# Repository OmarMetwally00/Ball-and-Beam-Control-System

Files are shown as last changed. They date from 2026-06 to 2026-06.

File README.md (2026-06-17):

# Ball and Beam Control System

<p align="center">
  
</p>

## Overview

The Ball and Beam System is a classical unstable control problem widely used in control engineering education and research. The objective is to control the position of a rolling ball along a beam by adjusting the beam inclination angle through a servo motor using a closed-loop PID controller.

This project presents the complete development cycle of a real Ball and Beam prototype following the **VDI 2206 Mechatronic Design Methodology**, including:

* Mechanical Design
* CAD Modeling
* Finite Element Analysis (FEA)
* Mathematical Modeling
* PID Controller Design
* MATLAB Simulation
* Simulink Simulation
* Arduino-Based Real-Time Control
* Hardware–Software Integration
* System Identification
* Experimental Validation

----

# Project Highlights

| Feature | Status |
| --- | --- |
| CAD Design | ✅ |
| Mechanical Analysis | ✅ |
| Finite Element Analysis | ✅ |
| Mathematical Modeling | ✅ |
| Transfer Function Derivation | ✅ |
| PID Controller Design | ✅ |
| MATLAB Simulation | ✅ |
| Simulink Simulation | ✅ |
| Arduino Implementation | ✅ |
| System Identification | ✅ |
| Experimental Validation | ✅ |
| VDI 2206 Methodology | ✅ |

---

# Hardware Prototype

<p align="center">
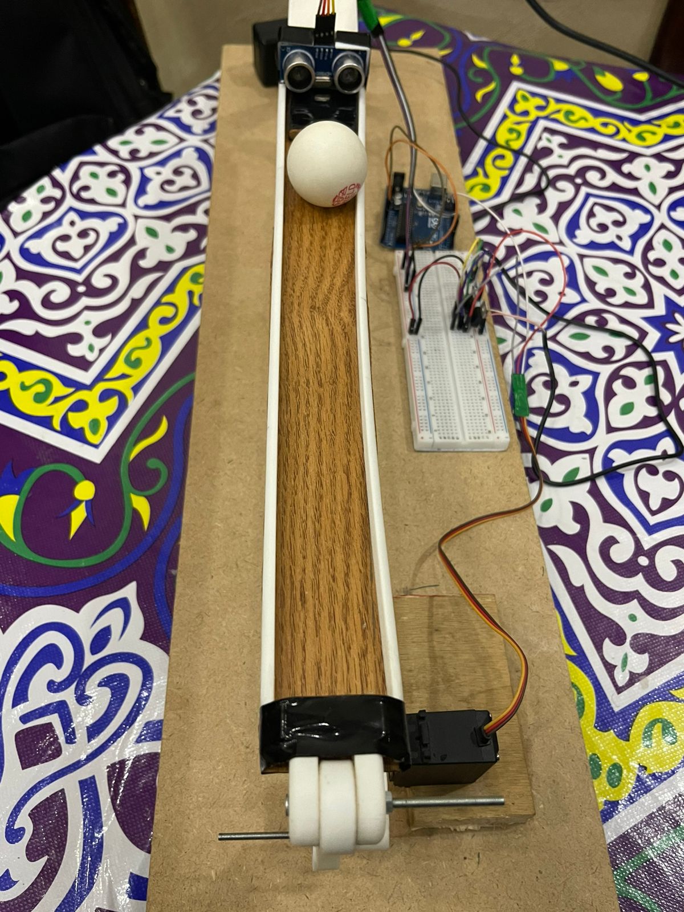
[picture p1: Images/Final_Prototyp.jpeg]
  
</p>

The physical prototype was developed and experimentally validated using:

* Arduino Uno
* MG995 Servo Motor
* HC-SR04 Ultrasonic Sensor
* Custom Mechanical Structure
* Voltage Regulation Circuit
* 12V Power Supply

---

# CAD Design

<p align="center">
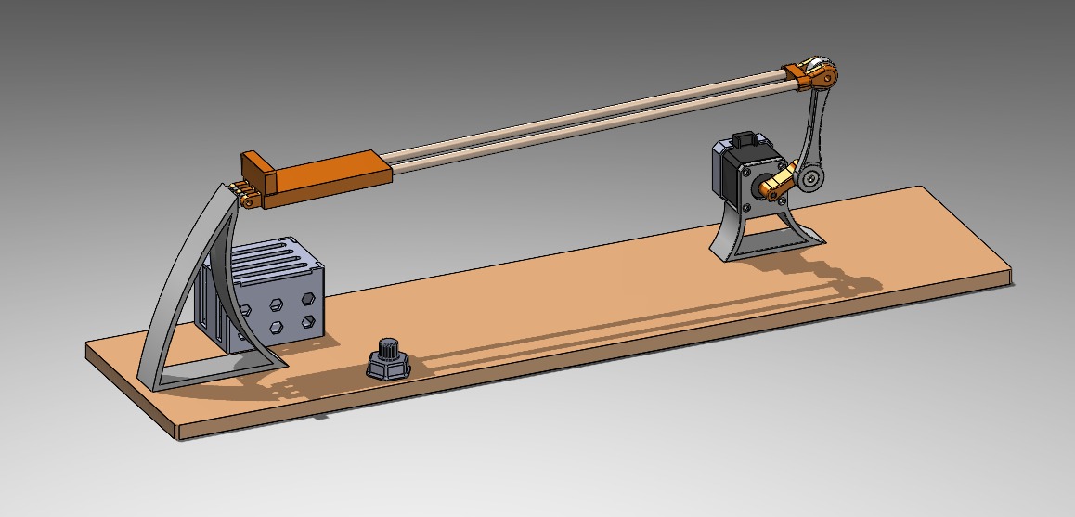
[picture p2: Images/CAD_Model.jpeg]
  
</p>

The complete mechanical assembly was designed and validated before fabrication.

Main subsystems include:

* Beam Assembly
* Linkage Mechanism
* Servo Mount
* Sensor Holder
* Structural Base

---

# System Architecture

```text
Reference Position
        │
        ▼
PID Controller
        │
        ▼
Arduino Uno
        │
        ▼
MG995 Servo Motor
        │
        ▼
Beam Angle
        │
        ▼
Ball Position
        │
        ▼
HC-SR04 Sensor
        │
        └──────────── Feedback
```

---

# Electronic Circuit

<p align="center">
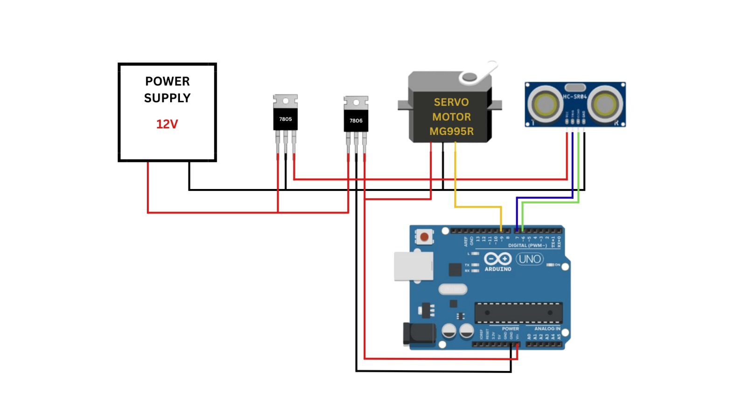
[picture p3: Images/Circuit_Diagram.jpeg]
  
</p>

The control system consists of an Arduino Uno, MG995 servo motor, HC-SR04 ultrasonic sensor, voltage regulation stage, and external power supply.

---

# VDI 2206 Engineering Workflow

The project was developed following the VDI 2206 methodology for mechatronic systems design.

This approach integrates:

1. Requirements Definition
2. Mechanical Design
3. Electronics Design
4. Software Development
5. System Integration
6. Validation and Testing

---

# Mathematical Modeling

The Ball and Beam system behaves as a double integrator and is inherently unstable in open-loop operation.

Plant Transfer Function:

P(s) = 5.532 / s²

This characteristic requires feedback control to stabilize the ball position.

---

# Control System Design

## Open-Loop Behavior

The open-loop response demonstrates unstable system behavior where the ball position continuously diverges from the desired position.

<p align="center">
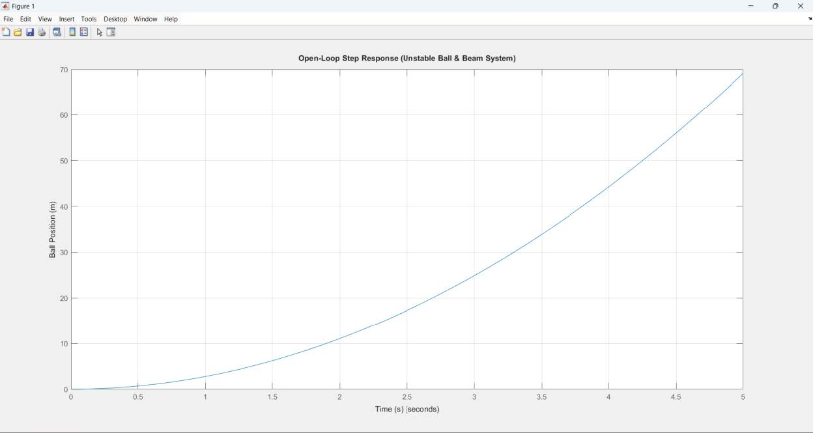
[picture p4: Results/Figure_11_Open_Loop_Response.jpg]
  
</p>

---

## Root Locus Analysis

Root locus analysis was used to investigate system stability and select suitable controller parameters.

<p align="center">
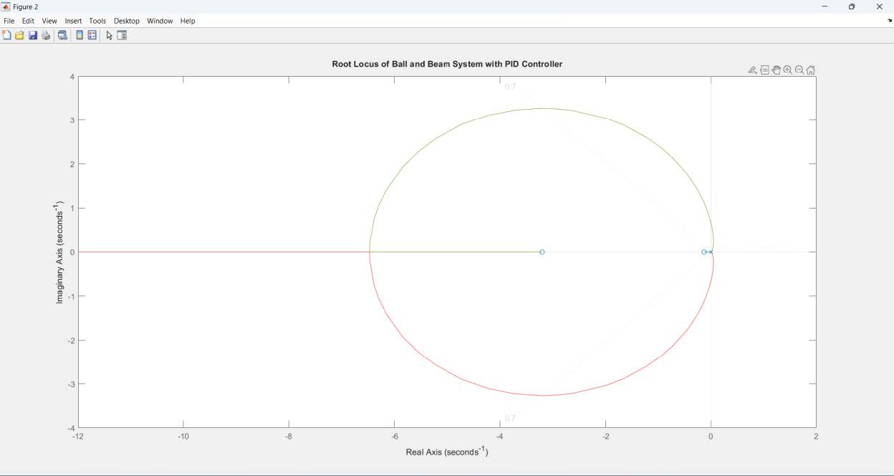
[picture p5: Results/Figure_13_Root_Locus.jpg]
  
</p>

---

## PID Controller Design

Selected controller gains:

```matlab
Kp = 40
Ki = 5
Kd = 12
```

These values provided a good balance between:

* Fast Response
* Small Overshoot
* Zero Steady-State Error
* Acceptable Settling Time

---

## Closed-Loop Response

The PID controller successfully stabilized the system and achieved accurate ball position tracking.

<p align="center">
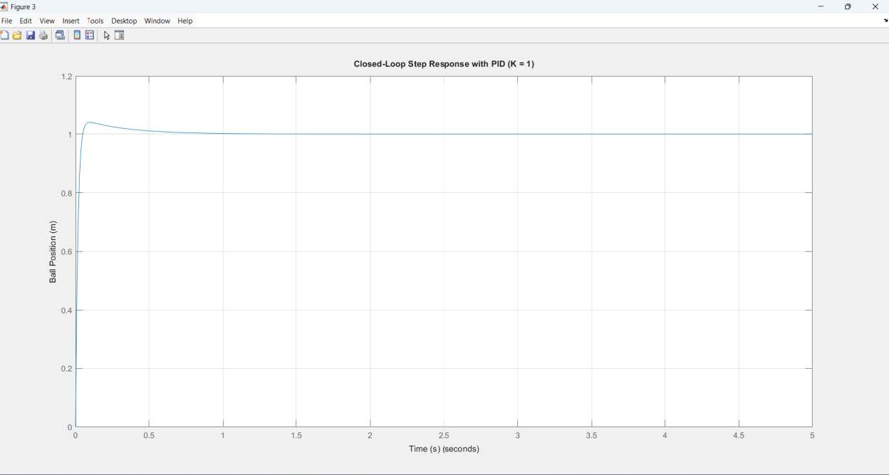
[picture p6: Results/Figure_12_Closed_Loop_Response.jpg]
  
</p>

---

# PID Tuning Analysis

## Effect of Proportional Gain (Kp)

<p align="center">
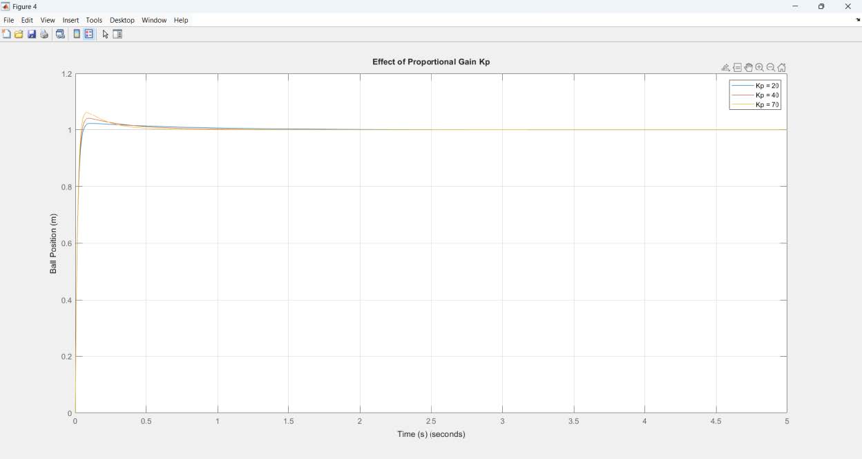
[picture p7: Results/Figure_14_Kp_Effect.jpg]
  
</p>

Increasing Kp improves response speed but may increase overshoot.

---

## Effect of Integral Gain (Ki)

<p align="center">
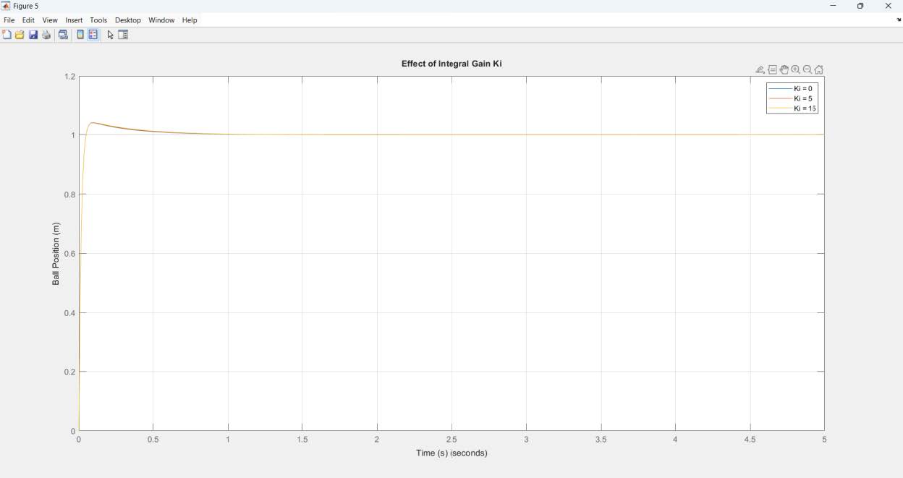
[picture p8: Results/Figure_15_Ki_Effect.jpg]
  
</p>

Increasing Ki reduces steady-state error and improves tracking accuracy.

---

## Effect of Derivative Gain (Kd)

<p align="center">
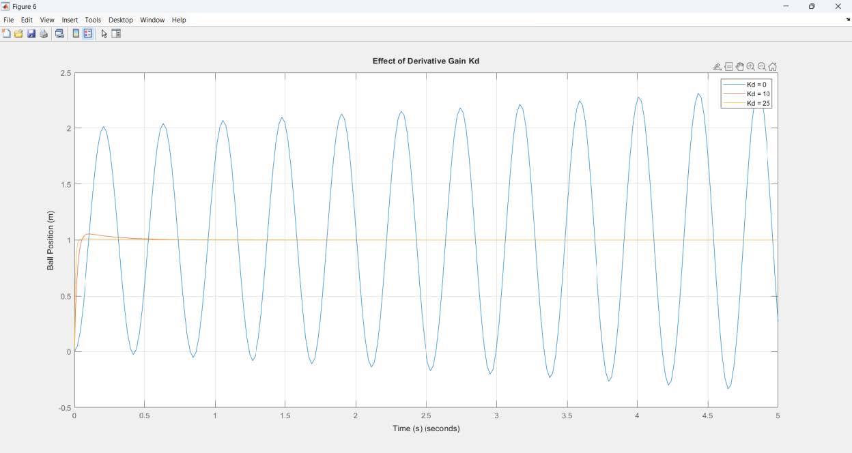
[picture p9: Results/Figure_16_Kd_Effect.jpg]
  
</p>

Derivative action increases damping and reduces oscillations.

---

# Simulink Modeling

## Open-Loop Simulink Model

<p align="center">
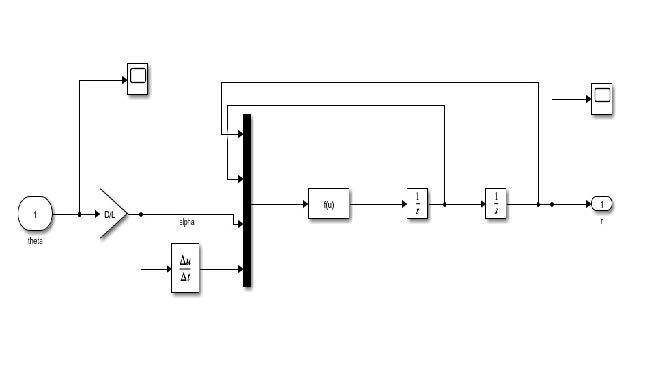
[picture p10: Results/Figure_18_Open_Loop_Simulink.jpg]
  
</p>

---

## Closed-Loop Simulink Model

<p align="center">
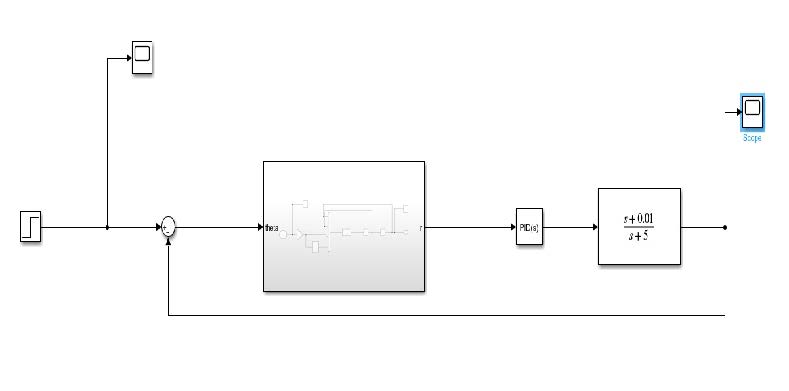
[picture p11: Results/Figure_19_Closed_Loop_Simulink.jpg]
  
</p>

---

# Hardware–Software Integration

The PID controller was implemented on Arduino and connected to MATLAB using serial communication.

Features:

* Real-time data acquisition
* Live response visualization
* Closed-loop monitoring
* Performance analysis

<p align="center">
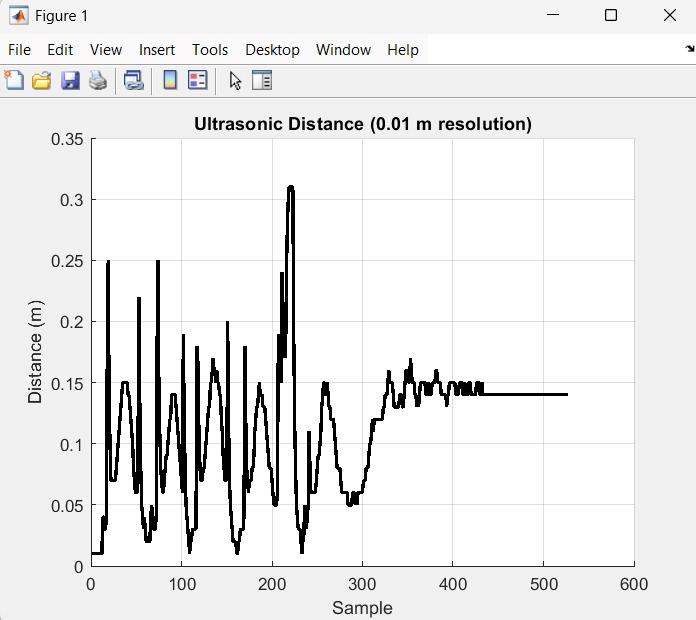
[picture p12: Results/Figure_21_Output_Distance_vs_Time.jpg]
  
</p>

---

# System Identification

Experimental data were collected from the physical prototype and processed using MATLAB System Identification Toolbox.

Identified Models:

Model 1

P(s) = (1.625s + 2.959) / (s² + 15.09s + 12850)

Model 2

P(s) = (25.05s + 39.11) / (s² + 87.88s + 1.494 × 10⁻¹⁰)

---

## System Identification Toolbox

<p align="center">
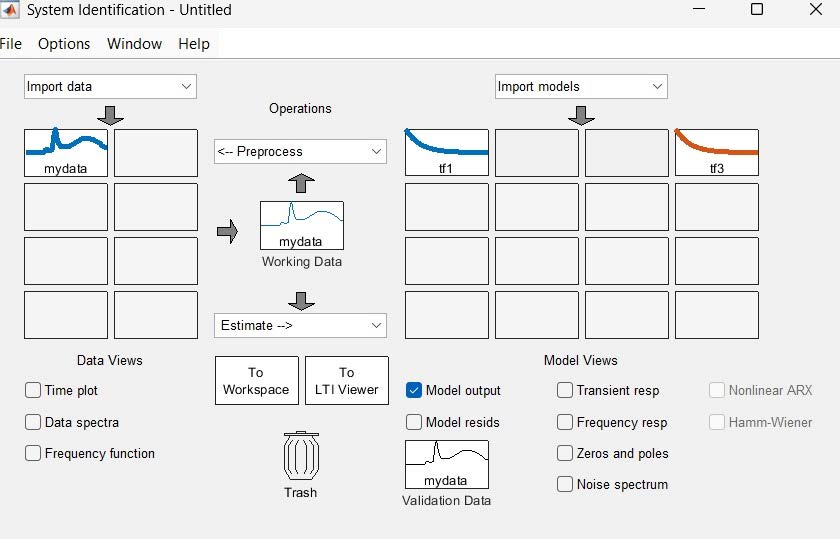
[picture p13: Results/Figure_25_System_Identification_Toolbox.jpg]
  
</p>

---

# Theoretical vs Practical Validation

One of the most important contributions of this project is the comparison between theoretical and experimentally identified models.

<p align="center">
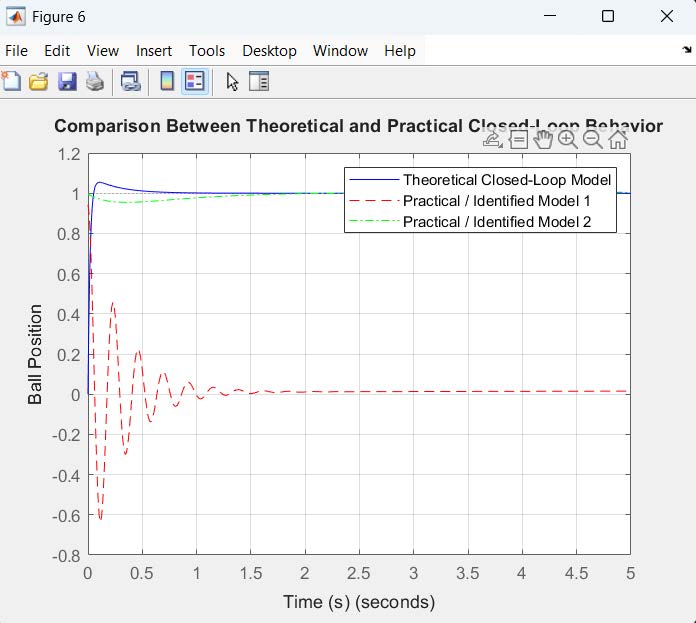
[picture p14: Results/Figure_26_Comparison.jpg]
  
</p>

---

## Performance Comparison

| Model | Overshoot (%) | Settling Time (s) | Steady-State Error |
| --- | --- | --- | --- |
| Theoretical Model | 5.43 | 0.364 | 0 |
| Practical Model 1 | 0.00 | 1005.137 | 0 |
| Practical Model 2 | 0.77 | 0.000 | 0 |

---

# Finite Element Analysis (FEA)

## Connecting Link Displacement

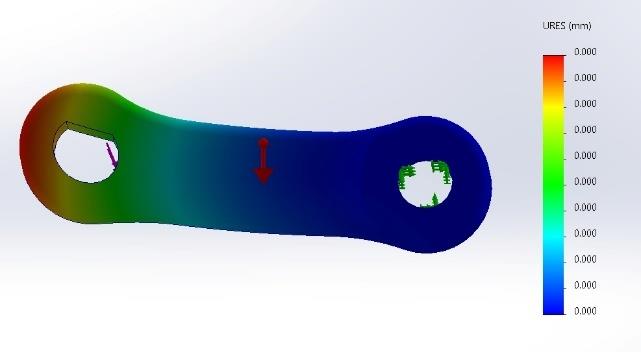
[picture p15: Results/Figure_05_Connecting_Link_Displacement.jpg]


## Connecting Link Stress Distribution

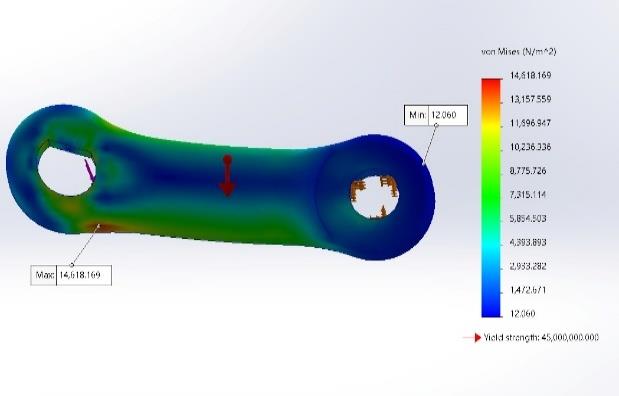
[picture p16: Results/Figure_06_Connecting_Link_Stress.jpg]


## Mesh and Boundary Conditions



## Beam Stress Distribution

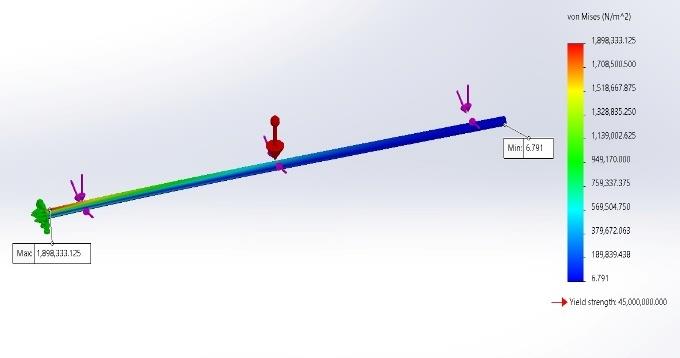
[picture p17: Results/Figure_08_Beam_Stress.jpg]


## Beam Displacement Distribution

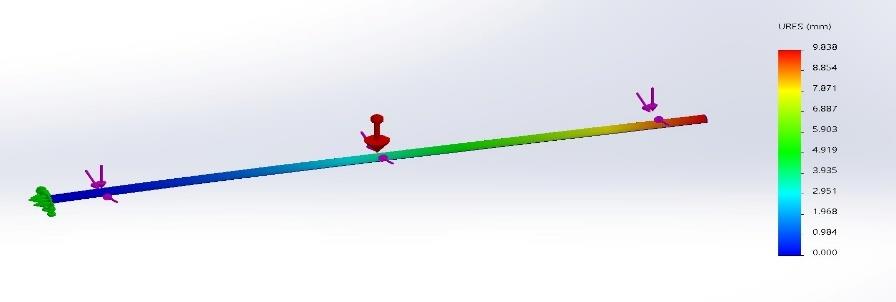
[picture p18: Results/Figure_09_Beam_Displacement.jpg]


---

# Team Members

* Mahmoud Mohamed Shamekh
* Omar Mahmoud Metwally
* Youssef Mostafa Ayad
* Ebrahim Magdy Ebrahim

---

# Supervision

Dr. Amro Shafik

Eng. Mohamed Ashraf

---

# License

This repository is published for educational, academic, and research purposes.

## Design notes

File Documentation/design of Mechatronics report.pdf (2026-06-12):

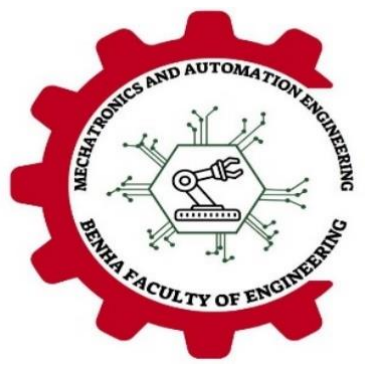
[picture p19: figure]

### 12 June 2026

Benha University

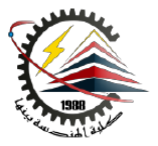
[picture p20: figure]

Benha Faculty of Engineering

Mechatronics and Automation Engineering Program

MAM 301 Design of Mechatronics

Design project

Student names: Mahmoud Mohamed Shamekh

Omar Mahmoud Metwally

Youssef Mostafa Ayad

Ebrahim Magdy Ebrahim

Supervisor Name: Dr/ Amro Shafik

Eng/ Mohamed Ashraf

Symbol | Description | Unit
( x ) | Ball position along the beam | m
( x ̇ ) | Ball linear velocity | m/s
( x ̈) | Ball linear acceleration | m/s²
( α ) | Beam inclination angle | rad
( α̇ ) | Beam angular velocity | rad/s
( α̈) | Beam angular acceleration | rad/s²
( θ ) | Servo motor shaft angle | rad
( θ ̇ ) | Servo motor angular velocity | rad/s
(θ ̈ | Servo motor angular acceleration | rad/s²
( m ) | Mass of the ball | kg
( mb ) | Mass of the beam | kg
( r ) | Radius of the ball | m
( L ) | Length of the beam | m
( R ) | Distance from beam pivot to ball | m

( d ) | Lever arm length | m
( J ) | Moment of inertia of the ball | kg·m²
( Jb ) | Moment of inertia of the beam | kg·m²
( Jm ) | Motor rotor inertia | kg·m²
( g ) | Gravitational acceleration | m/s²
( τ ) | Applied torque | N·m
( τm ) | Motor torque | N·m
( Va ) | Motor armature voltage | V
( Ia ) | Motor armature current | A
( Ra ) | Motor armature resistance | Ω
( La ) | Motor armature inductance | H
( Kt ) | Motor torque constant | N·m/A
( Ke ) | Motor back-EMF constant | V·s/rad
( b ) | Equivalent viscous damping coefficient | N·s/m
( bm ) | Motor viscous damping coefficient | N·m·s/rad
( Ff ) | Friction force | N
( P(s) ) | Ball and Beam plant transfer function | m/rad
( C(s) ) | PID controller transfer function | —
( Kp ) | Proportional gain | —
( Ki ) | Integral gain | —
( Kd ) | Derivative gain | —
( ωn ) | Natural frequency | rad/s
( ζ ) | Damping ratio | —
( e{ss} ) | Steady-state error | —

# Abstract

This project presents the systematic design, modeling, simulation, and implementation of a

Ball and Beam control system following the VDI 2206 V-Model for mechatronic system

development. The Ball and Beam system represents a classical unstable control problem that

integrates mechanical design, electronics, sensing, and control engineering. The primary

objective is to achieve accurate and stable positioning of a rolling ball along a beam by

regulating the beam angle using a feedback control strategy.

The development process begins with needs analysis and product design specifications,

followed by conceptual design and component selection. A mathematical model of the system

is derived using Newtonian mechanics, considering the rolling dynamics of the ball and small-

angle approximations. Based on the obtained model, a PID controller is designed to stabilize

the inherently unstable system and meet performance requirements such as low overshoot,

short settling time, and minimal steady-state error. MATLAB/Simulink is used for system

simulation and controller tuning, while Hardware-in-the-Loop (HIL) techniques are applied to

validate the control strategy before real-time implementation.

Finally, the controller is implemented on an Arduino microcontroller, and experimental results

are compared with simulation outcomes. The results demonstrate good agreement between

theoretical, simulated, and practical behavior, confirming the effectiveness of the V-Model

approach in developing a reliable mechatronic control system.

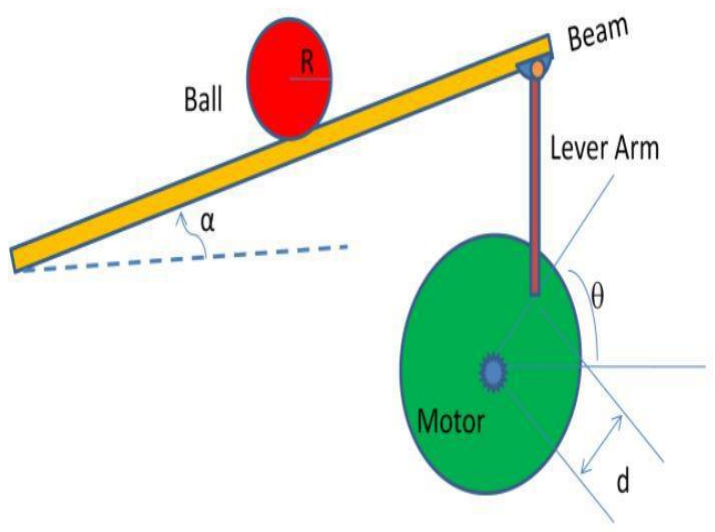
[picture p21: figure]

# Conceptual Design for Ball and Beam system

### 1. Problem Definition[2]

The objective of the Ball and Beam system is to

control the position of a ball along a beam by

adjusting the beam’s inclination angle using an

actuator. The control goal is to balance the ball at a

desired position or make it track a reference position

with high accuracy.

### 2. System Objectives

1. Maintain stable balance of the ball on the beam without falling
2. Accurately control the ball position
3. Provide fast response to disturbances and reference changes
4. Allow easy tuning and calibration

### 3. System Needs

- Continuous measurement of the ball position
- Precise adjustment of the beam angle
- Real-time execution of the control algorithm
- Data visualization and/or logging
- High accuracy and stability
- Reliable operation
- Reasonable cost for educational use
- Electrical and mechanical safety

### 4. System Specifications

Parameter | Specification | Parameter | Specification
Beam Length (L) | 35cm | Controller | PID
Ball Radius (r) | 15–20 mm | Power Supply | 12 V DC
Ball Mass (m) | 50–100 g | microcontroller | Arduino
Beam Angle Range (α) | ±15° | Overshoot | < 10%
Position Accuracy | ±2 mm | Actuator | Servo Motor MG995
Settling Time | < 3 s | Sensor | Ultrasonic

### 5. Constraints

### 5.1 Safety Constraints

- Mechanical end-stops to limit beam rotation
- Electrical insulation and proper grounding
- Overcurrent and overvoltage protection

### 5.2 Environmental Constraints

- Indoor laboratory operation only
- Operating temperature range: 0–40 °C
- Low vibration and dust-free environment
- No exposure to moisture or corrosive substances

### 5.3 Manufacturability Constraints

- Use of commercially available components
- Simple machining processes (3D printing)
- Modular design for easy assembly and replacement
- Low manufacturing and maintenance cost

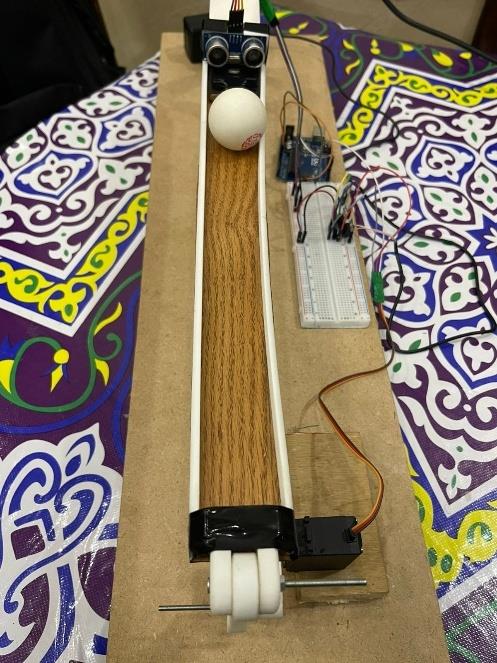
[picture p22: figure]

Figure 1:the system

6.

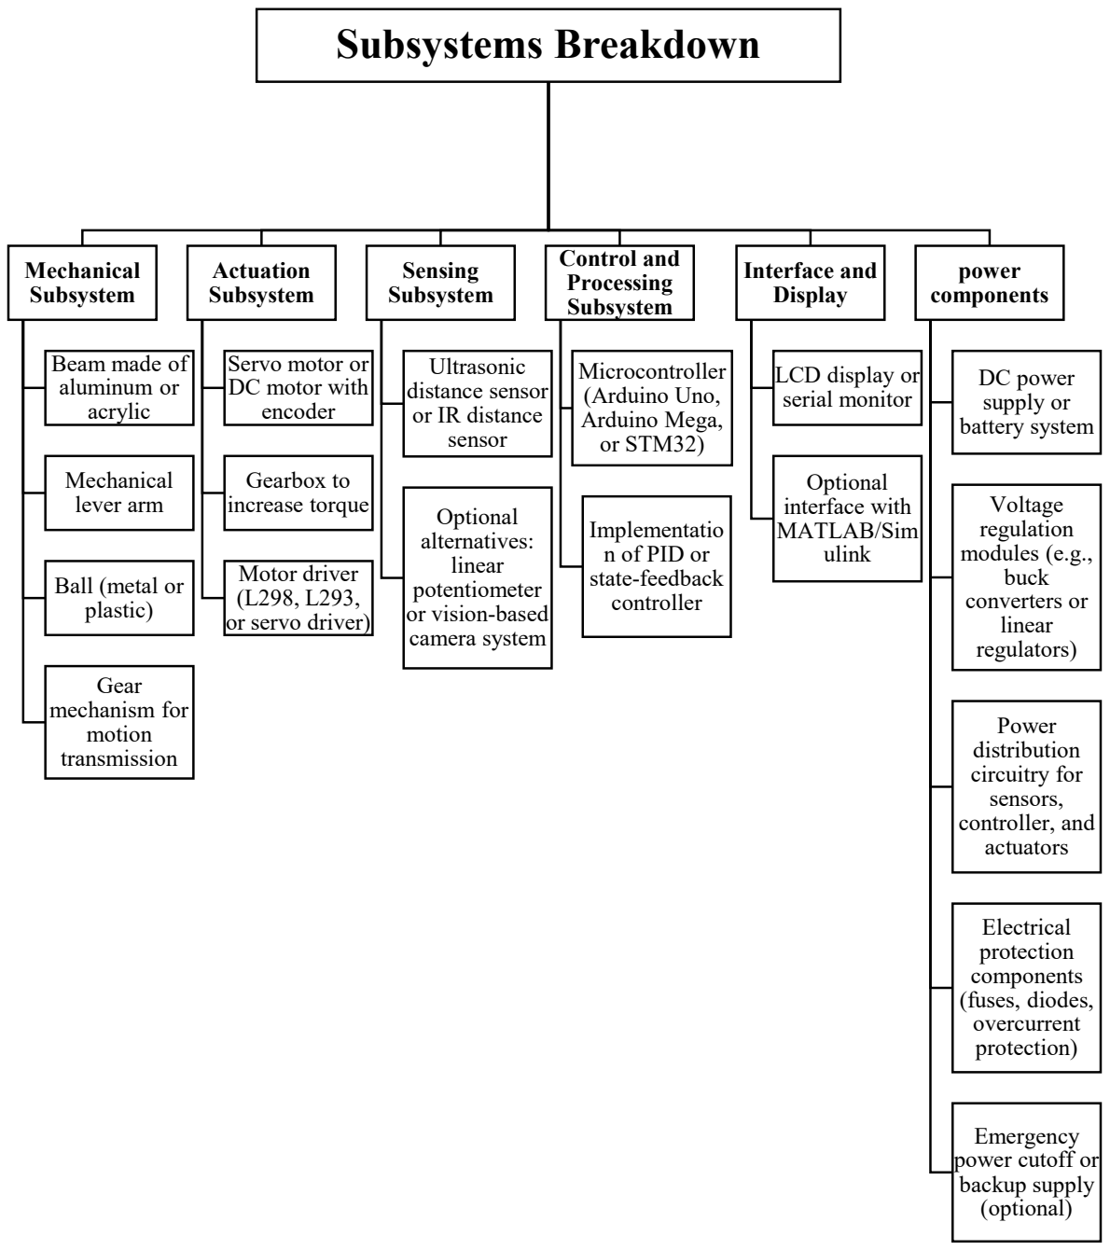
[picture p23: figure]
Subsystems Breakdown; Mechanical Subsystem; Beam made of aluminum or acrylic; Mechanical lever arm; Ball (metal or plastic); Gear mechanism for motion transmission; Actuation Subsystem; Servo motor or DC motor with encoder; Gearbox to increase torque; Motor driver (L298, L293, or servo driver); Sensing Subsystem; Ultrasonic distance sensor or IR distance sensor; Optional alternatives: linear potentiometer or vision-based camera system; Control and Processing Subsystem; Microcontroller (Arduino Uno, Arduino Mega, or STM32); Implementatio n of PID or state-feedback controller; Interface and Display; LCD display or serial monitor; Optional interface with MATLAB/Sim ulink; power components; DC power supply or battery system; Voltage regulation modules (e.g., buck converters or linear regulators); Power distribution circuitry for sensors, controller, and actuators; Electrical protection components (fuses, diodes, overcurrent protection); Emergency power cutoff or backup supply (optional)

### 7. Design Alternatives

Design Alternative | DA₁ | DA₂ | DA₃
Sensor Type | Ultrasonic | IR Sensor | Camera Vision
Actuator | Servo Motor | DC Motor + Encoder | Stepper Motor
Control Method | PID | PI | State-Space
med Controller | Arduino Uno | Arduino Mega | STM32
Cost | Medium | High | High
Complexity | Low | Medium | High

### 8. Design Evaluation Criteria

Criterion | Weight | DA1 | DA2 | DA3
Accuracy | 0.30 | 0.7 | 0.9 | 0.6
Stability | 0.40 | 0.9 | 0.7 | 0.6
Cost | 0.10 | 0.9 | 0.5 | 0.6
Ease of Implementation | 0.20 | 0.6 | 0.8 | 0.7
evaluation | 1 | 0.78 | 0.76 | 0.66

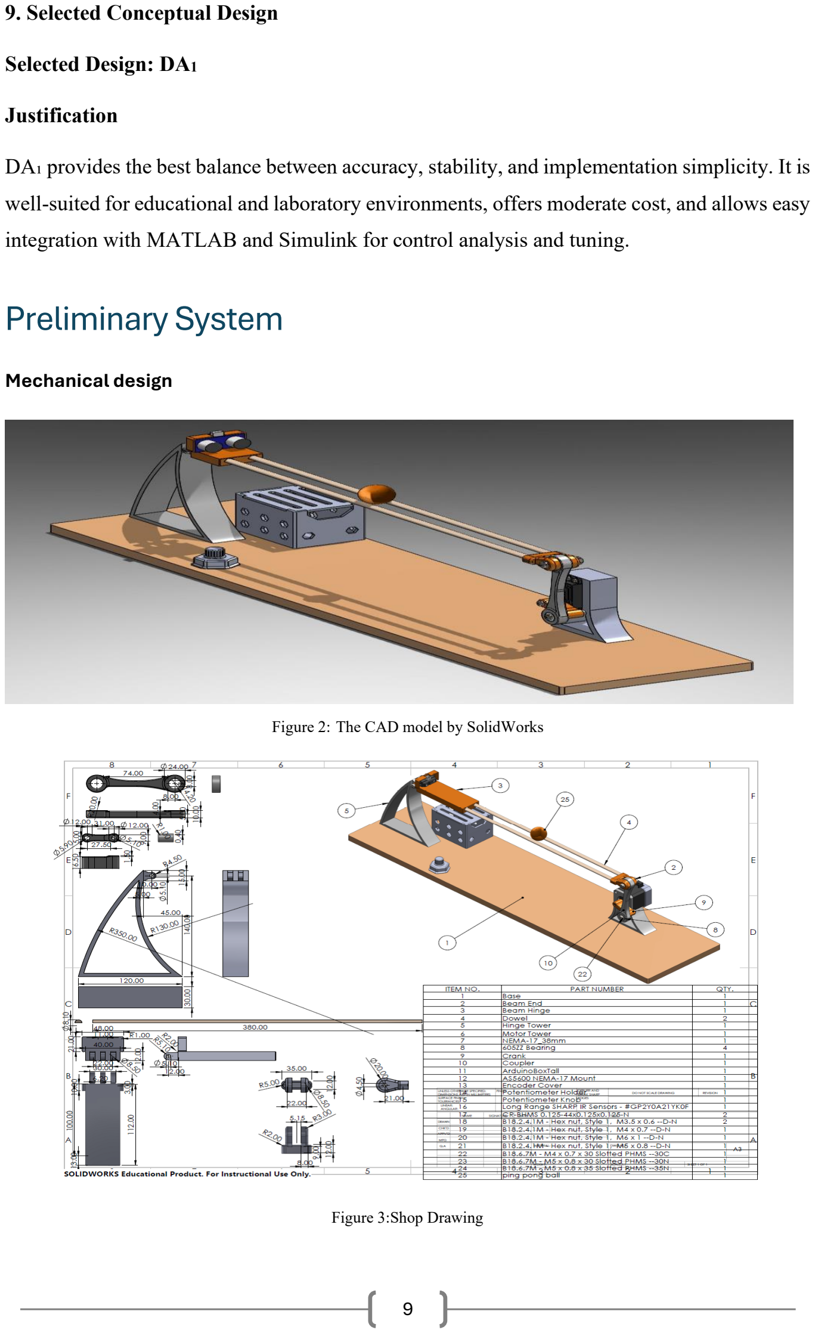
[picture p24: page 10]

### 9. Selected Conceptual Design

Selected Design: DA1

Justification

DA₁ provides the best balance between accuracy, stability, and implementation simplicity. It is

well-suited for educational and laboratory environments, offers moderate cost, and allows easy

integration with MATLAB and Simulink for control analysis and tuning.

# Preliminary System

### Mechanical design

Figure 2: The CAD model by SolidWorks

Figure 3:Shop Drawing

2.preliminary electronic/control circuit diagram

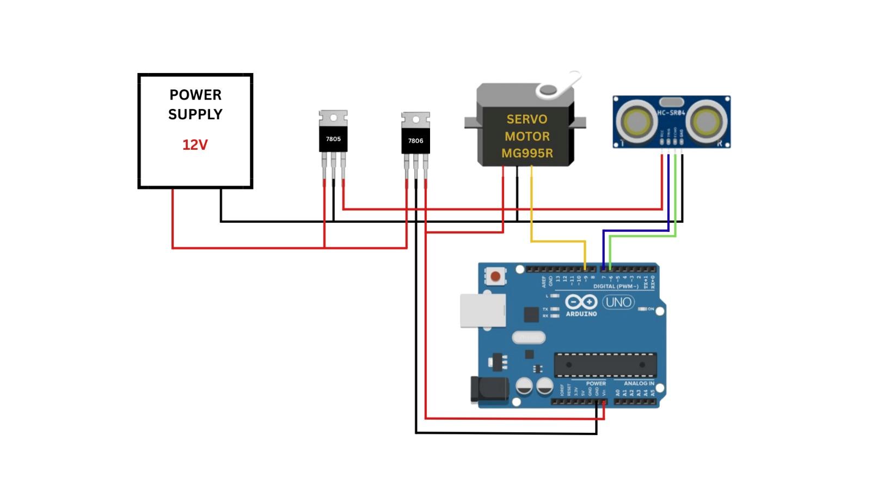
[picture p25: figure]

Figure 4:Circuit diagram

3.All components and their interfaces

No. | Component | Type | Function in System | Input Interface | Output Interface | Interface Type
1 | Ball | Mechanical | Object to be balanced on the beam | Beam inclination angle (α) | Ball position (x) | Mechanical (Contact & Gravity)
2 | Beam | Mechanical | Supports the ball and transfers tilt motion | Rotation from lever arm | Linear motion of the ball | Mechanical (Rotational → Translational)
3 | Lever Arm | Mechanical | Converts servo rotation to beam tilt | Servo shaft rotation (θ) | Beam angular displacement (α) | Mechanical (Rotational Linkage)

4 Servo | Motor (MG995R) | Actuator | Controls beam angle | PWM signal from Arduino | Shaft rotation (θ) | Electrical (PWM) → Mechanical
5 Ultrasonic | Sensor (HC-SR04) | Sensor | Measures ball position on beam | Trigger pulse from Arduino | Echo pulse proportional to distance | Digital Electrical (Trigger/Echo)
6 Arduino | Uno | Controller | Main control and signal processing unit | Sensor signals (Echo), Power (5V) | PWM to servo, Trigger to sensor | Digital Electrical
7 Control | Algorithm (PID) | Software | Stabilizes ball position | Ball position error | Control signal (PWM duty cycle) | Logical / Software Interface
8 Power | Supply (12V DC) | Electrical | Provides power to system | AC/DC input | 12V DC output | Electrical Power
9 Voltage | Regulator (7805) | Electrical | Steps down voltage for logic | 12V DC | 5V DC | Electrical Power
10 Voltage | Regulator (7806) | Electrical | Steps down voltage for servo | 12V DC | 6V DC | Electrical Power

11 Mechanical | Base & Frame | Structural | Supports all components | Static loads | Structural stability | Mechanical
12 Wiring & | Connectors | Electrical | Signal & power transmission | Electrical signals | Electrical signals | Electrical

# Mechanical Design, Kinematics, and FEA

System Overview

The finalized mechanical design of the balanced beam system consists of a servo-actuated

crank–link mechanism that converts the rotational motion of the MG995 servo motor into a

controlled angular displacement of the beam. The beam is hinged at one end and supports a

rolling ball used to demonstrate balancing and control concepts.

### 2. Geometry & Dimensions

Component | Dimension
Crank length | 4.2 cm
Link length | 11.2 cm
Beam length | 35 cm
Beam cross-section | Semi-circular, Ø 8 mm
Hinge height | 14 cm
Servo rotation range | 0–180°
Beam rotation range | ±10° (approx.)

Note: All dimensions were selected to avoid singular configurations and mechanical

interference.

Material Selection

Component | Material | Reason
Beam | PLA | Lightweight, sufficient strength, easy fabrication
Link & Crank | PLA | Low inertia, ease of manufacturing
Base | Wood | Structural stability

Note: PLA provides adequate strength with a high factor of safety while minimizing weight.

Kinematic Relation

θs → Servo motor | ∅ → Link Angle | θb → Beam angle

Crank length (r)=.042m

Beam Length (lb)=.35m | | Link Length (L)=.112m

Links Analysis

Position Analysis

r cos(θS) + L cos(∅) = lb cos(θb) | | Horizontal direction
r sin(θS) + L sin(∅) = lb sin(θb) | | Vertical direction
| θb = tan⁻¹ r sin(θS) + L sin(∅) r cos(θS ) + L cos(∅)

Velocity Analysis

r θs

∙

| cos(θS) + L ∅ ∙ cos(∅) = lb θb

∙
cos(θb)

r θs

∙

| sin(θS) + L ∅ ∙ sin(∅) = lb θb

∙
sin(θb)

Acceleration Analysis

r θs

∙∙
| (−sin(θS)) + L ∅

∙∙
(sin(∅))

Ball analysis

Position

Yball = xsin(θb)

Velocity

Yball

- = xcos(θb
)θb

̇

Accelerate

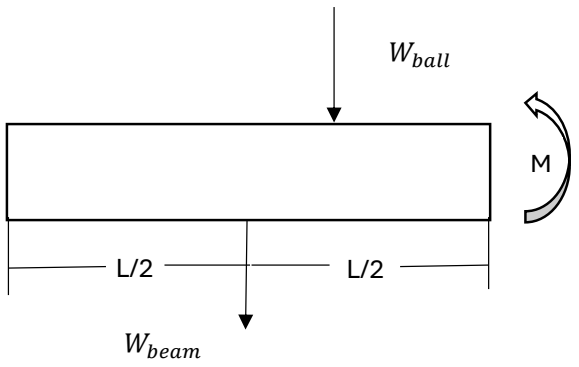
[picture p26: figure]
Wball; Wbeam

Yball ⃛ = −sinθbθb

̇

2
+ cosθbθb

̈

Dynamics

Wball = mg

Wbeam = mbeamg

Ibeam =

1
3

mblb

2 =

1
3

∗ .011 ∗ (. 35)

2 = 4.5 × 10⁻⁴

∑τ = Iθb

τball = mgxcos(θb

) | τbeam = mbeamg

l
2

cos(θb

)

∴ τeq − gcos(θb)(mballx + mbeam

l
2

) = Ibeamθb

at θbvery small → cos(θb

) = 1

at θ = 0

τmax = 9.81 ∗ (. 003x + .011 ∗ .175)

= .02943x + .0189333

at x = .35m

τ = .036 ≅ .04N/m

We selectMG995 Servo motor

Max Tourq for Servo ≈ 1.1 N/m (∴ Suitable for system)

Stress Analysis

Mmax = mballgx + mbeam

l
2

I = .11r

4 = .11(. 004)

4 = 2.8 × 10⁻¹¹m⁴

σbeam =

Mmax ∗ c
I

(at x = l)

Mmax = 9.81(. 003 ∗ .35 + .11 ∗ .175) = .029N. m

σbeam =

.029∗004
2.8∗10⁻¹¹ = 4.1 MPa | (bending stress)

V=(mball + mbeam)g = (. 003 + .011) ∗ 9.81 = .137N

τmax =

4V
3A

A =

πr

2

2

τmax = 1.1 MPa | (Shear stress)

σeq = √σbeam
2 | + 3τmax
2 | = 4.1 MPa

Summary

Stress Analysis Summary

- Maximum bending stress:

σmax ≈ 4.1 MPa

- PLA yield stress:

σy ≈ 50 MPa

- Factor of Safety:

FOS ≈ 12

Design is structurally safe.

Actuator Verification

- Required torque:

τreq ≈ 0.04 N ⋅ m

### Beam Cross Section 8∅

- MG995 available torque:

τstall ≈ 1.1 N ⋅ m

Servo motor selection is adequate with a large torque margin.

Finite Element Analysis (FEA)

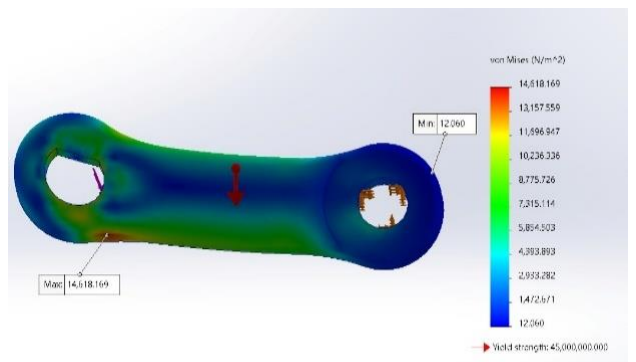
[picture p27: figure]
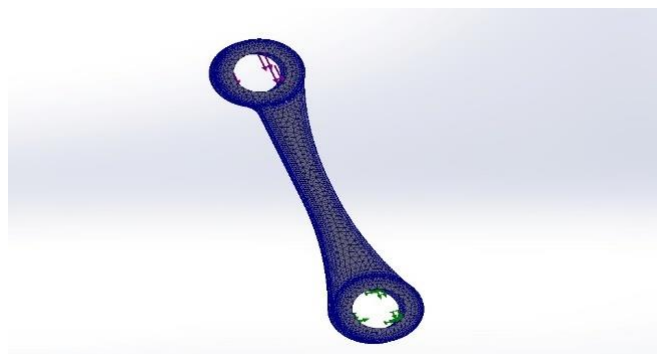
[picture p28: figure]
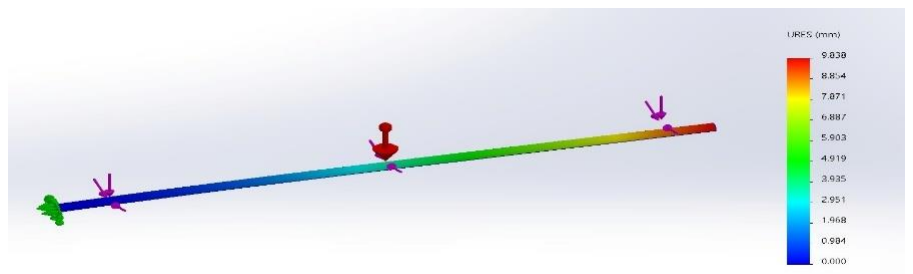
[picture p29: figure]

Figure 5 illustrates the total displacement (URES) distribution of the connecting link under the

applied load. One end of the link is constrained, while a downward force is applied near the

centre to represent the transmitted load from the crank–servo mechanism. The displacement

increases gradually from the fixed end toward the free end, reaching its maximum value at the

Figure 7:Finite element mesh and boundary conditions of the connecting link

Figure 8 : von Mises stress distribution of the beam under applied loading

Figure 9:Total displacement (URES) distribution of the beam under applied loading

Figure 5:Total displacement (URES) of the connecting link

Figure 6:von Mises stress distribution of the connecting link under applied load unconstrained side. The smooth colour gradient indicates uniform deformation without

localized instability. The overall displacement magnitude is very small, confirming that the

link has sufficient stiffness and is suitable for use in the ball and beam system.

Figure 6 shows the von Mises stress distribution of the connecting link obtained from finite

element analysis. One end of the link is constrained, while a downward load is applied to

simulate the force transmitted from the servo-driven crank mechanism. The stress is mainly

concentrated around the hole regions due to stress concentration effects caused by pin

connections. The maximum von Mises stress reaches approximately 14.6 MPa, which is

significantly lower than the material yield strength of 45 MPa. This confirms that the

connecting link operates safely without risk of plastic deformation under the applied loading

conditions.

Figure 7 shows the finite element model of the connecting link, including the applied mesh

and boundary conditions. A triangular mesh is used to accurately represent the complex

geometry of the link, with finer elements around the holes where stress concentration is

expected. The lower hole is fully constrained to simulate the fixed joint, while forces are

applied at the upper hole to represent the load transmitted from the servo-driven crank

mechanism. This meshing and boundary condition setup ensures reliable stress and

displacement results in the finite element analysis.

Figure 8 illustrates the von Mises stress distribution along the beam obtained from finite

element analysis. The beam is constrained at one end, while external forces are applied at the

mid-span and near the free end to represent the combined effect of the linkage force and the

ball weight. The maximum von Mises stress, approximately 1.9 MPa, occurs near the fixed

support due to the highest bending moment. All stress values are significantly below the

material yield strength of 45 MPa, indicating that the beam operates safely under the applied

loading conditions.

Figure 9 presents the total displacement (URES) distribution along the beam obtained from

finite element analysis. The beam is fixed at one end, while downward forces are applied at the

mid-span and near the free end to represent the effect of the ball weight and the linkage force.

The displacement increases gradually from the fixed support toward the free end, reaching a

maximum value of approximately 9.8 mm at the free end. This deformation pattern is

consistent with classical beam bending behaviour and remains within acceptable limits for the

ball and beam control system.

FEA Summary

The finite element analysis confirms that:

- Maximum stress in all components is well below the yield strength.
- Displacements are within acceptable limits for accurate ball position control.
- Stress concentrations occur mainly at holes and fixed supports, as expected.
- The mechanical design is structurally safe and suitable for the ball and beam system

driven by the MG955 servo motor

Final Mechanical Model Validation

The final mechanical design satisfies:

- Kinematic requirements
- Dynamic and torque constraints
- Stress and deflection limits
- Manufacturing feasibility

The system is therefore mechanically complete and ready for control implementation and experimental

testing.

The mechanical design of the balanced beam system has been finalized after verifying kinematic

performance, actuator capability, and structural integrity. The design meets all functional and safety

requirements and provides a reliable platform for control system development.

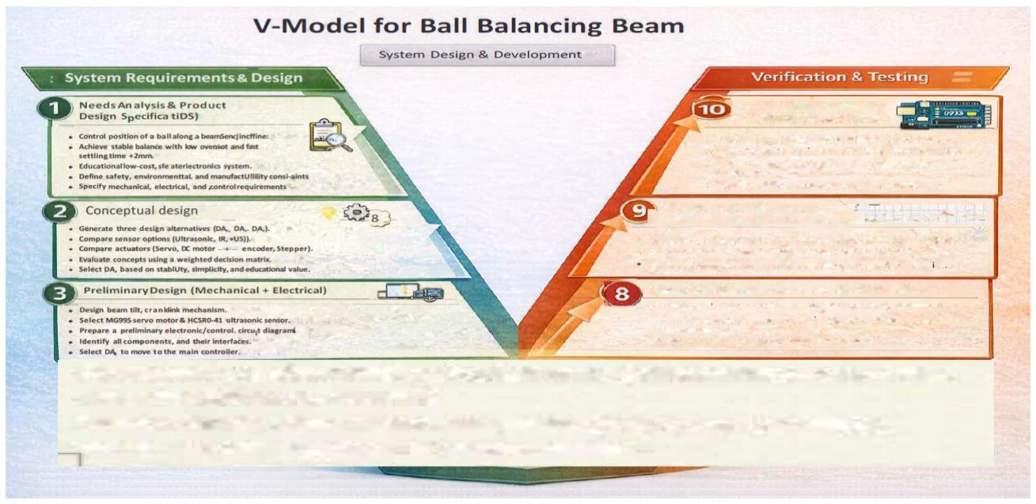
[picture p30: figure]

Figure 10: Left Side of the V-model

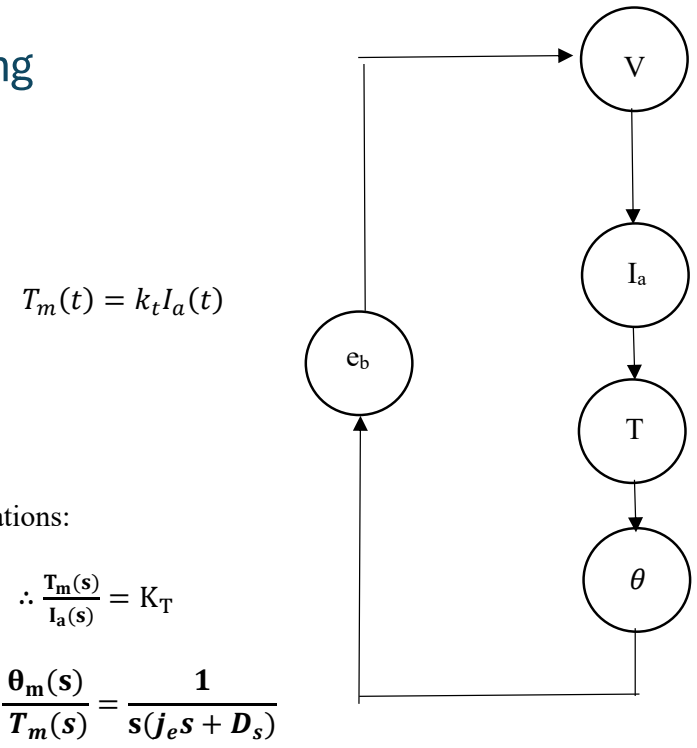
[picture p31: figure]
1 s(jes + Ds)

# Mathematical Modeling

Motor Modeling:

Va = La

Ia

∙
(t) + Ra
Ia

(t)

Tm(t) = jeθ

∙∙
m + Deθ

∙
m

eb = keθ

∙

by take LaPlace and sub. all the equations:

∴

I(s)
Va(s)

=

1
Las+Ra

∴

By putting the equations in Simulink

G =

KT
S(LaJeS

2 + (JeRa + DeLa
)S + RaDe)

System Equations [10]

The second derivative of the input beam angle αα affects the second derivative of the ball

position rr. However, this contribution is neglected for simplicity. The Lagrangian equation

of motion of the ball on the beam is given by:

0 = (

J
R2 +m) r̈+ mgsin α − mrα̇
2

Linearizing this equation about the equilibrium beam angle α = 0α=0, the following linear

approximation of the system is obtained:
(

J
R2 +m) r̈= −mgα

The relationship between the beam angle αα and the gear (servo) angle θθ can be

approximated by the linear relation:

α =

d
L

θ

By Substituting Equation:
(

J
R2 +m) r̈= −mg

d
L

θ

Transfer Function

Taking the Laplace transform of Equation (4), assuming zero initial conditions, gives:
(

J
R2 +m) s
2R(s) = −mg

d
L

Θ(s)

Rearranging, the transfer function from the gear angle Θ(s)Θ(s) to the ball

position R(s)R(s) is obtained as:

P(s) =

R(s)
Θ(s)

=

mgd
L (

J
R2 +m)

1
s

2 m/rad

For Our system

m = 0.0027 | Ball mass (kg)
L = 0.35 | Beam length (m)

R = L - 0.02 Distance from pivot (m)

d = 0.042 Lever arm length (m)

J = 8× 10

−7 | Ball moment of inertia (kg.m^2)
g = 9.81 | Gravity (m/s^2)

MATLAB Simulation

% ============================================================ % Benha University
% Faculty of Engineering
% Mechatronics and Automation Engineering Program % MAM 301 - Design of Mechatronics % Design Project: Ball and Beam System

% Students:
% Mahmoud Mohamed Shamekh
% Omar Mahmoud Metwally
% Youssef Mostafa Ayad
% Ebrahim Magdy Ebrahim

% Supervisors:
% Dr. Amro Shafik
% Eng. Mohamed Ashraf
% ============================================================

clc; clear; close all;

%% ============================================================ % Physical Parameters
%% ============================================================
M = 0.0027; | % Ball mass (kg)
L = 0.35; | % Beam length (m)
R = L - 0.02; | % Distance from pivot (m)
D = 0.042; | % Ball diameter (m)
r = D/2; | % Ball radius (m)
J = 8e-7; | % Ball moment of inertia (kg.m^2)
g = -9.81; | % Gravity acceleration (m/s^2)

%% ============================================================ % Ball & Beam Model Constants
%% ============================================================
A = (J/(r^2)) + M; | % Effective mass term
K = (M * g * R) / L; | % System constant

%% ============================================================ % Transfer Function
%% ============================================================ s = tf('s');

% Ball position / Beam angle transfer function
P = -(K/A) * 1/(s^2);

disp('Ball and Beam Plant Transfer Function:') P

%% ============================================================ % Open-Loop Response (Unstable)
%% ============================================================ figure
step(P,5)
grid on
title('Open-Loop Step Response (Unstable Ball & Beam System)') xlabel('Time (s)')
ylabel('Ball Position (m)')

%% ============================================================ % PID Controller Parameters
%% ============================================================
Kp = 40; | % Proportional gain
Ki = 5; | % Integral gain
Kd = 12; | % Derivative gain

% PID controller (transfer function form, without scalar gain) C0 = Kp + Ki/s + Kd*s;

%% ============================================================ % Root Locus with Variable Gain K
%% ============================================================ figure
rlocus(C0 * P)
grid on
title('Root Locus of Ball and Beam System with PID Controller') sgrid(0.7, []) % Desired damping ratio

%% ============================================================ % Gain Selection
%% ============================================================
K_gain = 1; | % Selected from root locus (adjust if needed)

C_final = K_gain * C0;
T_final = feedback(C_final * P, 1);

%% ============================================================ % Closed-Loop Response
%% ============================================================ figure
step(T_final,5)
grid on
title(['Closed-Loop Step Response with PID (K = ', num2str(K_gain), ')']) xlabel('Time (s)')
ylabel('Ball Position (m)')

%% ============================================================ % Effect of PID Parameters
%% ============================================================ % ---- Effect of Kp ----
Kp_vals = [20 40 70];
figure; hold on
for kp = Kp_vals
Ctemp = kp + Ki/s + Kd*s;
Ttemp = feedback(Ctemp * P, 1); step(Ttemp,5)
end
legend('Kp = 20','Kp = 40','Kp = 70') grid on
title('Effect of Proportional Gain Kp') xlabel('Time (s)')
ylabel('Ball Position (m)')

% ---- Effect of Ki ----
Ki_vals = [0 5 15];
figure; hold on
for ki = Ki_vals
Ctemp = Kp + ki/s + Kd*s;
Ttemp = feedback(Ctemp * P, 1); step(Ttemp,5)
end
legend('Ki = 0','Ki = 5','Ki = 15') grid on
title('Effect of Integral Gain Ki') xlabel('Time (s)')
ylabel('Ball Position (m)')

% ---- Effect of Kd ----
Kd_vals = [0 10 25];
figure; hold on
for kd = Kd_vals
Ctemp = Kp + Ki/s + kd*s;
Ttemp = feedback(Ctemp * P, 1); step(Ttemp,5)
end
legend('Kd = 0','Kd = 10','Kd = 25') grid on
title('Effect of Derivative Gain Kd')
xlabel('Time (s)')
ylabel('Ball Position (m)')
%% ============================================================ % Stability Information (Poles & Damping Table)
%% ============================================================ [wn, zeta, poles] = damp(T_final);

ResultsTable = table( ...
poles, ...
zeta, ...
wn, ...
'VariableNames', {'Pole', 'DampingRatio', 'NaturalFrequency'} ... );

disp('Closed-Loop Poles and Damping Information:') disp(ResultsTable)

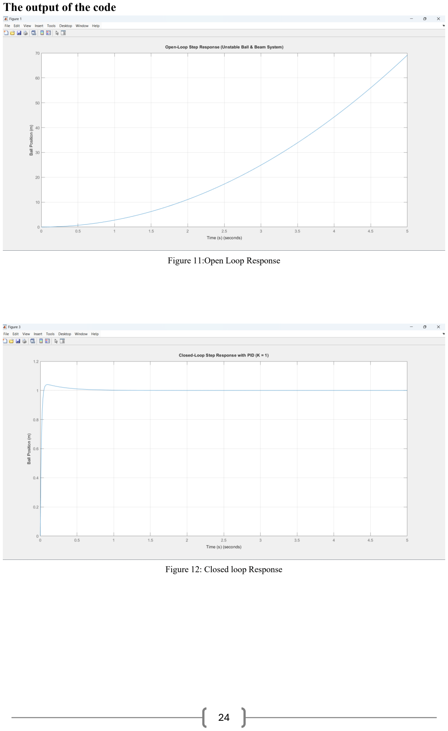
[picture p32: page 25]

The output of the code

Figure 11:Open Loop Response

Figure 12: Closed loop Response

Ball and Beam Plant Transfer Function:

P(s) =

5.532
s

2

Closed-Loop Poles and Damping Information:

Pole | Damping Ratio | Natural Frequency
-0.13007 | 1 | 0.13007
-3.3825 | 1 | 3.3825
-62.876 | 1 | 62.876

Figure 11 illustrates the open-loop step response of the ball and beam system. The response

shows that the ball position increases rapidly and continuously with time without reaching a

steady value. This unbounded growth is caused by the double integrator nature of the plant,

which makes the system unstable in open-loop operation. Any small input disturbance results

in continuous acceleration of the ball along the beam, confirming that feedback control is

essential to stabilize the system and prevent the ball from diverging.

Figure 12 presents the closed-loop step response of the ball and beam system when a PID

controller is applied. The response demonstrates a stable behavior where the ball position

quickly reaches the desired reference value with a small overshot and then settles smoothly

without sustained oscillations. The steady-state error is effectively eliminated due to the

integral action, while the derivative term provides sufficient damping. This result confirms

that the selected PID controller parameters successfully stabilize the ball and beam system

and significantly improve its transient and steady-state performance compared to the open-

loop case.

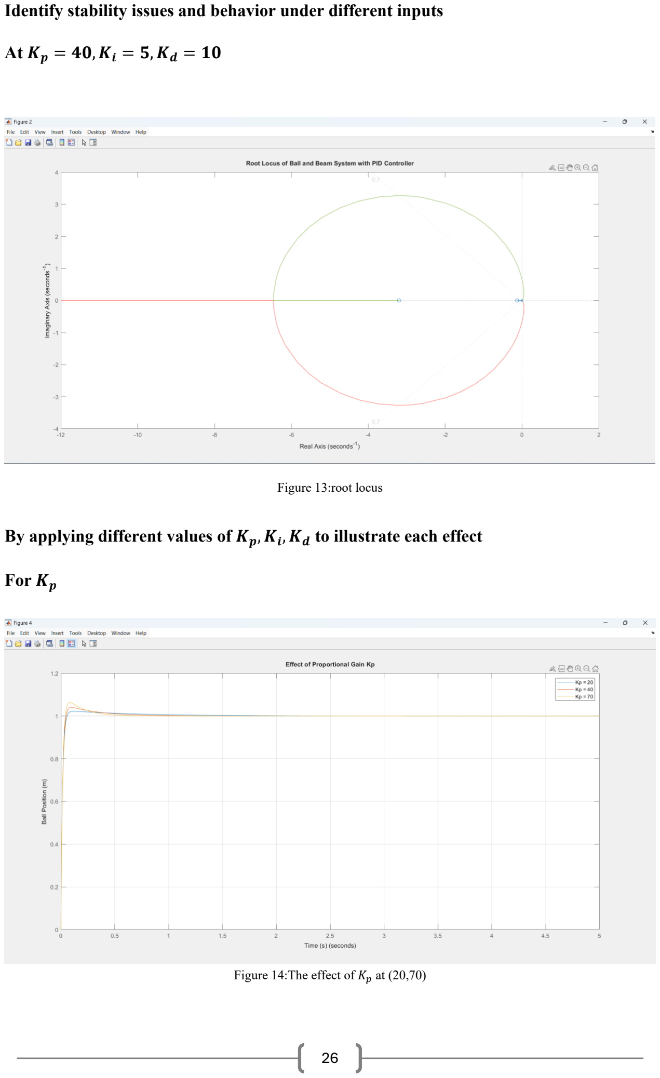
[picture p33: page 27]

Identify stability issues and behavior under different inputs

At Kp = 40, Ki = 5, Kd = 10

By applying different values of Kp, Ki

, Kd to illustrate each effect

For Kp

Figure 13:root locus

Figure 14:The effect of Kp at (20,70)

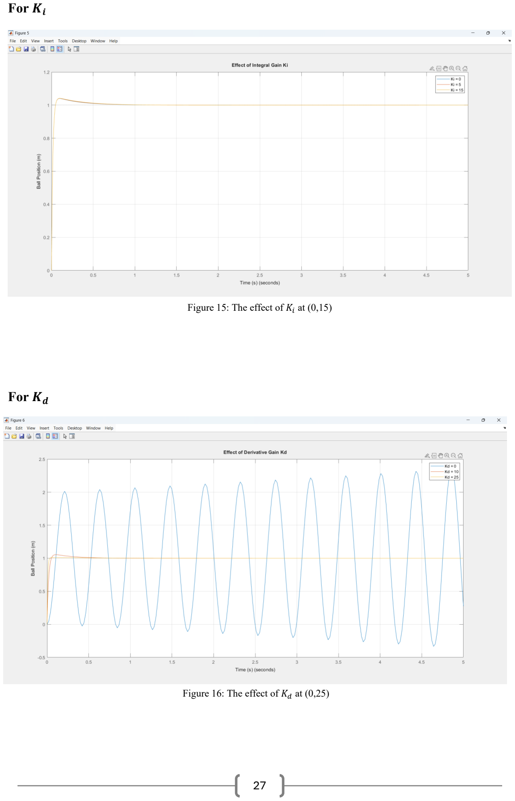
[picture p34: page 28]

For Ki

For Kd

Figure 15: The effect of Ki at (0,15)

Figure 16: The effect of Kd at (0,25)

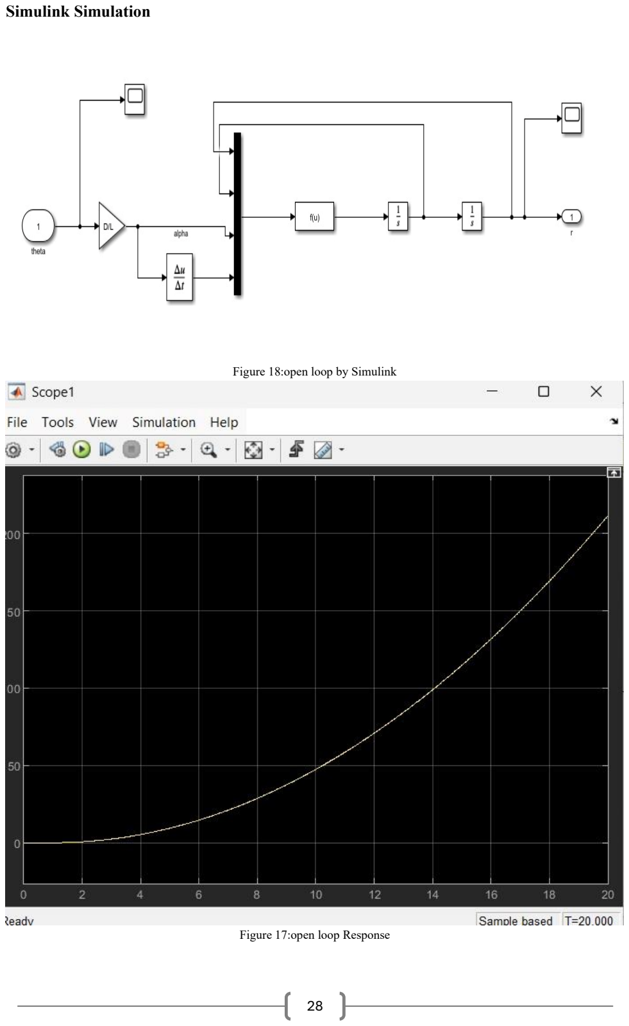
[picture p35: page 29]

Simulink Simulation

Figure 18:open loop by Simulink

Figure 17:open loop Response

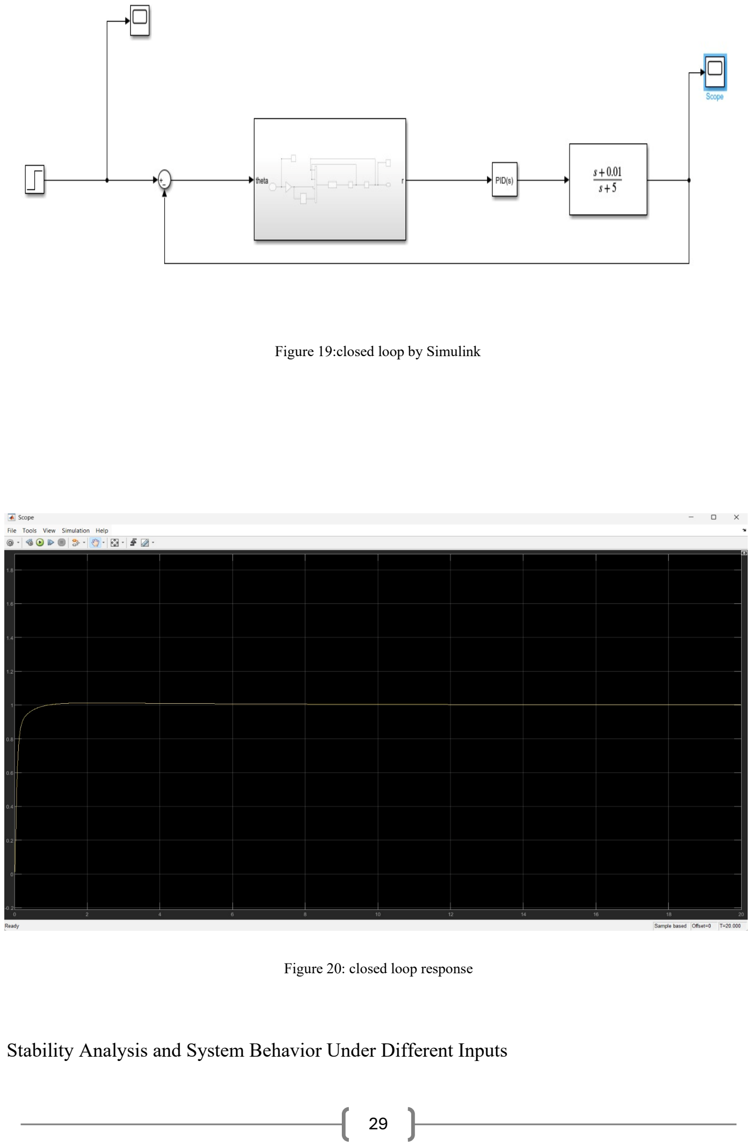
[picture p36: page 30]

Stability Analysis and System Behavior Under Different Inputs

Figure 20: closed loop response

Figure 19:closed loop by Simulink

The open-loop step response of the ball and beam system clearly demonstrates that the system

is unstable. As shown in the open-loop response figure, the ball position increases rapidly and

diverges with time due to the double integrator nature of the plant. This confirms that without

feedback control, the ball cannot be stabilized on the beam, and any small input leads to

unbounded motion.

When the PID controller with gains Kp = 40, Ki = 5, and Kd = 10 is applied, the closed-loop

step response shows stable and well-damped behavior. The ball position reaches the desired

reference with a small overshoot and settles quickly without sustained oscillations. This

indicates that the selected PID parameters successfully stabilize the system and provide

acceptable transient performance.

The root locus plot further supports this observation, as all closed-loop poles are in the left half

of the complex plane for the chosen gain, with a damping ratio close to the desired value (ζ ≈

0.7). This confirms that the closed-loop system is stable and adequately damp.

The effect of varying the proportional gain Kpshows that increasing Kpimproves the response

speed but also increases overshoot. Low values of Kp result in slower responses, while

excessively high values lead to more aggressive behavior. An intermediate value of Kp =

40 provides a good balance between fast response and acceptable overshoot.

The effect of the integral gain Kidemonstrates its role in eliminating steady-state error.

When Ki = 0, a small steady-state error is observed. Increasing Ki
reduces this error and

ensures accurate tracking of the reference position. However, very large values of Ki may

slightly increase overshoot and slow down the settling process.

The effect of the derivative gain Kdhighlights its importance in damping the system.

With Kd = 0, the response exhibits large oscillations and poor stability. As Kd increases,

oscillations are significantly reduced, and the response becomes smoother. Higher derivative

gains improve damping but must be carefully selected to avoid excessive sensitivity to noise.

Finally, the Simulink simulation results confirm the MATLAB analytical results. The open-

loop Simulink model shows unstable behavior, while the closed-loop PID-controlled model

stabilizes the ball position effectively. The consistency between MATLAB simulations and

Simulink models validates the correctness of the mathematical model and the chosen PID

control parameters.

# Hardware–Software Integration and Data Visualization

In this work, the PID controller was implemented on an Arduino microcontroller using an

embedded program. The Arduino was interfaced with MATLAB through serial

communication, enabling real-time data exchange between the hardware controller and the

simulation environment. The control signal and system output were transmitted via the serial

port, where MATLAB received and processed the incoming data. A dedicated MATLAB script

was developed to read the serial data stream and generate time-domain plots of the system

output. This approach allowed real-time visualization and analysis of the system response,

facilitating direct observation of the closed-loop behaviour and performance of the Ball and

Beam system.

Arduino code

#include <Servo.h>

#define Umax 66

#define Umin -66

#define Umax_rad 1.151

#define Umin_rad -1.151

#define T 0.09

const int echoPin1 = 3;
const int trigPin1 = 2;
Servo servo;
// ================= Variables =================
double setpoint = 0.20; | // 20 cm ) | (
double setpoint_prec = 0.20;
double y, y_prec;
double error;
double P, I, D, U;
double I_prec = 0, D_prec = 0; boolean Saturation = false;

// ================= PID Gains ================= double Kp = 25;
double Ki = 17;
double Kd = 140;

// ================= Functions ================= float measure_1(void);
void move_servo(int);

//========================================== unsigned long t_prev = 0;
const unsigned long Ts = 10; // 10 ms = 0.01 s

//========================================== // ================= Setup ================= void setup() {

Serial.begin(9600);

pinMode(trigPin1, OUTPUT); pinMode(echoPin1, INPUT);

servo.attach(9);

delay(1000);
move_servo(90);
delay(2000);

y_prec = measure_1();
delay(1000);
}

// ================= Loop ================= void loop() {

// Measurement
y = measure_1();
y = 0.53 * y + 0.47 * y_prec; // Quantization 0.01
y = round(y * 100.0) / 100.0;

// Print
Serial.println(round(y * 100.0) / 100.0); // === PID ( ) ===
error = y - setpoint;
// Error
error = round(100 * (y - setpoint)) * 0.01;

// PID
P = Kp * error;

if (!Saturation)
I = I_prec + T * Ki * error;

D = (Kd / T) * (y - y_prec);
D = 0.56 * D + 0.44 * D_prec;

U = P + I + round(100 * D) * 0.01; // radians

// Saturation
if (U < Umin_rad) {
U = Umin_rad;
Saturation = true;
}
else if (U > Umax_rad) {
U = Umax_rad;
Saturation = true;
}
else {
Saturation = false;
}

// Convert to servo angle
U = round(U * 180 / M_PI);
U = map(U, Umin, Umax, 24, 156);

// Move servo only if needed
if (U < 83 || U > 95 || abs(error) > 0.02) move_servo(round(U));

delay(24);

// Update previous values
I_prec = I;
y_prec = y;
D_prec = D;
}

// ================= Ultrasonic Sensor ================= float measure_1(void) {

long elapsed_time = 0;
float distance = 0;

digitalWrite(trigPin1, LOW); delayMicroseconds(10);

digitalWrite(trigPin1, HIGH); delayMicroseconds(10);

digitalWrite(trigPin1, LOW);

elapsed_time = pulseIn(echoPin1, HIGH); distance = (float)elapsed_time / 58.2;

delay(30);

if (distance > 42) distance = 43;
else if (distance < 0) distance = 0;

return 0.01 * (distance - 1.5 + 0.5); // meters }

// ================= Servo =================
void move_servo(int u) {
u = constrain(u, 0, 180);
servo.write(u);
}

MATLAB Code

clc;
clear;
close all;

% serial
s = serialport("COM11", 9600); configureTerminator(s,"LF"); flush(s);

% drawing
figure;
h = animatedline('LineWidth',2); grid on;
xlabel('Sample');
ylabel('Distance (m)');
title('Ultrasonic Distance (0.01 m resolution)');

k = 0;

% storage data
xData = [];
yData = [];
constData = []; % contant distance 0.2m

C = 0.20;

% readings
while ishandle(h)
if s.NumBytesAvailable > 0 data = readline(s);
y = str2double(data);

if ~isnan(y)
k = k + 1;
xData(k,1) | = k;
yData(k,1) | = y;
constData(k,1) = C;

% plot
addpoints(h, k, y);
drawnow limitrate;
end
end
end

The output of the two codes give us plot for Output With time And The Desired distance

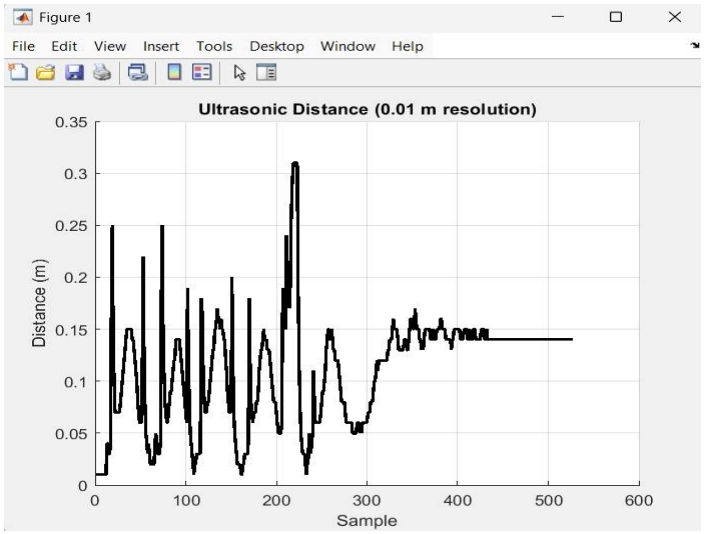
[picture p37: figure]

Figure 21:Output Distance with time

# System Identification & Parameter Estimation

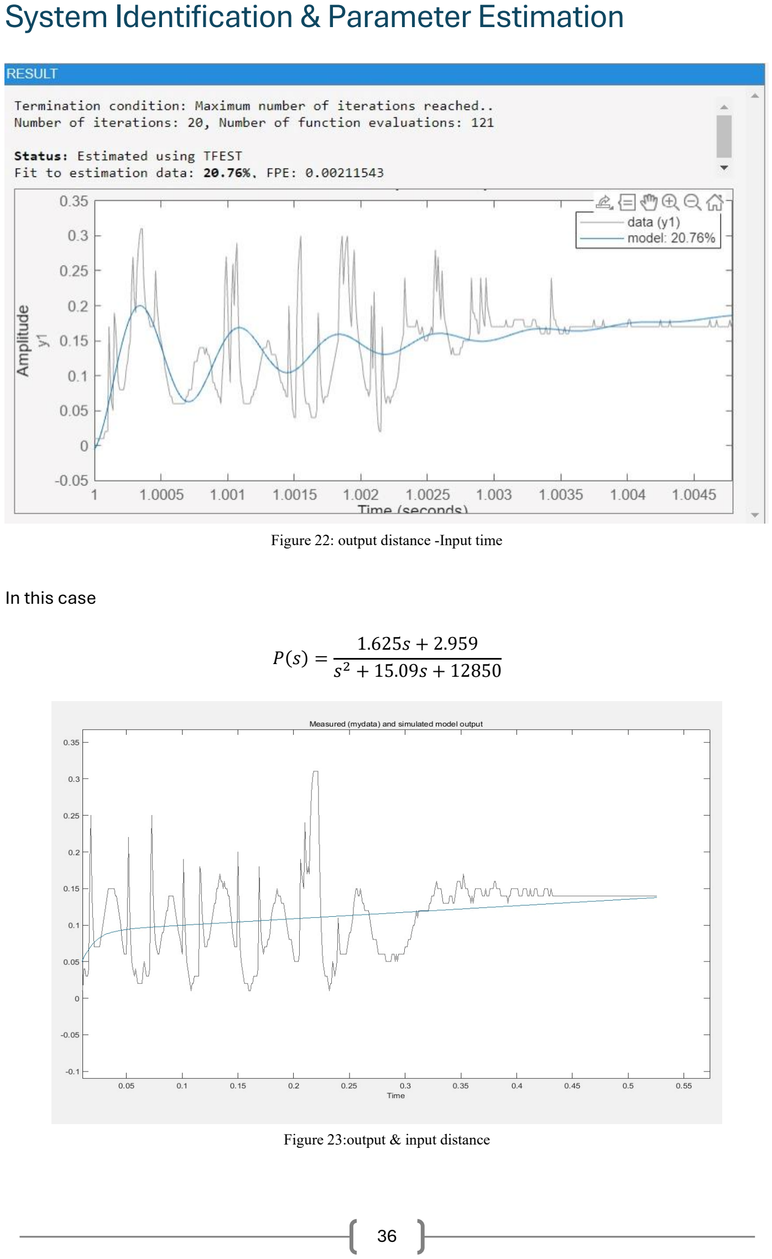
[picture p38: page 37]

### In this case

P(s) =

1.625s + 2.959
s

2 + 15.09s + 12850

Figure 22: output distance -Input time

Figure 23:output & input distance

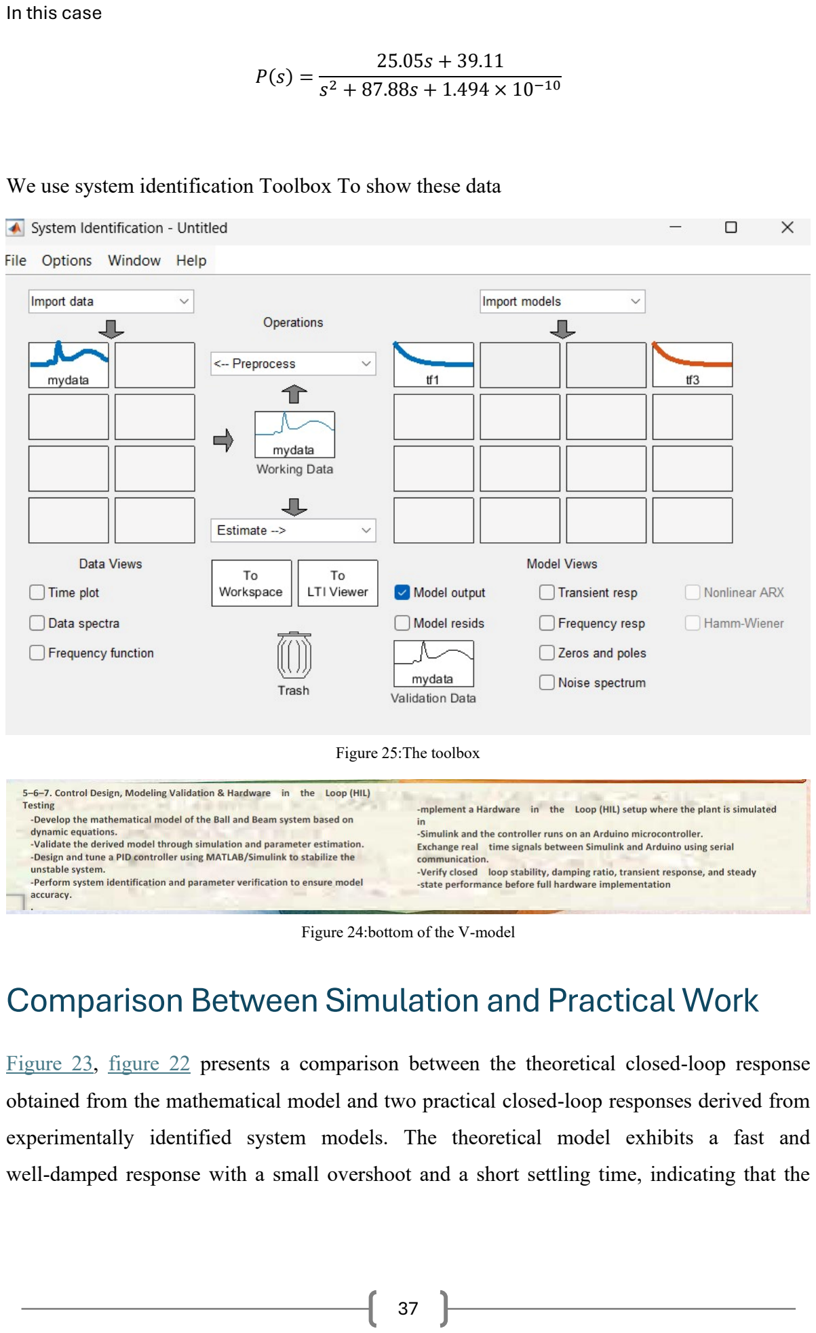
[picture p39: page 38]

### In this case

P(s) =

25.05s + 39.11
s

2 + 87.88s + 1.494 × 10⁻¹⁰

We use system identification Toolbox To show these data

# Comparison Between Simulation and Practical Work

Figure 23, figure 22 presents a comparison between the theoretical closed-loop response

obtained from the mathematical model and two practical closed-loop responses derived from

experimentally identified system models. The theoretical model exhibits a fast and

well-damped response with a small overshoot and a short settling time, indicating that the

Figure 25:The toolbox

Figure 24:bottom of the V-model designed PID controller achieves the desired stability and transient performance under ideal

modeling assumptions.

In contrast, the practical identified models show noticeable deviations from the theoretical

response. Practical Model 1 exhibits oscillatory behavior with a larger overshoot and longer

settling time, which can be attributed to unmodeled dynamics, actuator nonlinearities, and

delays in the real system. Practical Model 2 shows a slower response with reduced oscillations

but a slight steady-state deviation, reflecting the influence of parameter variations, friction, and

sensor inaccuracies.

The observed differences between the simulation and practical responses are mainly caused by

modeling errors, sensor noise, friction effects, and time delays that are not fully captured in the

theoretical model. Despite these differences, the overall trends of the responses confirm that

the PID controller successfully stabilizes the Ball and Beam system in both simulated and

practical scenarios. This comparison validates the effectiveness of the control design while

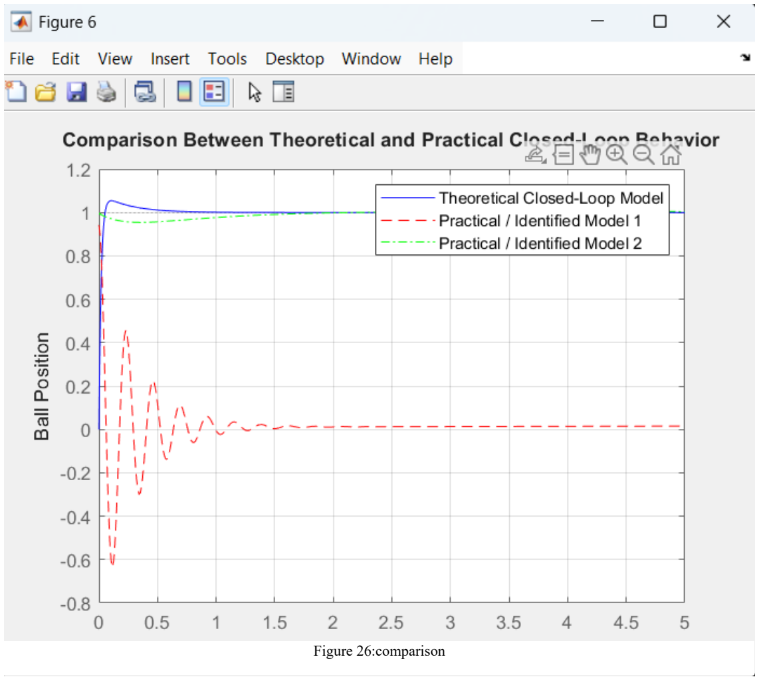
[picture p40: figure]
Figure 26:comparison

highlighting the importance of experimental identification and real-world testing in

mechatronic system development

Comparison between theoretical and practical behavior

%% ================== Performance Analysis ==================

% Step information
info_theoretical = stepinfo(T);
info_practical1 = stepinfo(T_practical);
info_practical2 = stepinfo(T_practical2);

% Steady-state values
ss_theoretical = dcgain(T); ss_practical1 = dcgain(T_practical); ss_practical2 = dcgain(T_practical2);

% Steady-state error (for unit step input) ess_theoretical = abs(1 - ss_theoretical); ess_practical1 = abs(1 - ss_practical1);
ess_practical2 = abs(1 - ss_practical2);

% Display results
fprintf('\n===== Closed-Loop Performance Comparison =====\n');

fprintf('\nTheoretical Model:\n');
fprintf('Overshoot = %.2f %%\n', info_theoretical.Overshoot); fprintf('Settling Time = %.3f s\n', info_theoretical.SettlingTime); fprintf('Steady-State Error = %.5f\n', ess_theoretical);

fprintf('\nPractical Model 1:\n');
fprintf('Overshoot = %.2f %%\n', info_practical1.Overshoot); fprintf('Settling Time = %.3f s\n', info_practical1.SettlingTime); fprintf('Steady-State Error = %.5f\n', ess_practical1);

fprintf('\nPractical Model 2:\n');
fprintf('Overshoot = %.2f %%\n', info_practical2.Overshoot); fprintf('Settling Time = %.3f s\n', info_practical2.SettlingTime); fprintf('Steady-State Error = %.5f\n', ess_practical2);
Model | Overshoot (%) | Settling Time (s) | Steady-State Error
Theoretical Model | 5.43 | 0.364 | 0.00000
Practical Model 1 | 0.00 | 1005.137 | 0.00000

System Parameters

Transfer Function Comparison

Theoretical | System identification
5.532 P(s) = 2 s | Distance to Distance | Time to distance
25.05s + 39.11 P(s) = 2 + 87.88s + 1.494 × 10⁻¹⁰ s | 1.625s + 2.959 P(s) = 2 + 15.09s + 12850 s
Parameter | Value | Units
(R) | 2.5 | Ω
(Kt) | 5.8857 × 10⁻³ | Nm/A
(Kω) | 169.9029 | rad/V
(Jm ) | 6.3173 × 10⁻⁷ | kg·m²
(N) | 275.6923 | —
(η) | 0.81156 | —
(bm) | 2.49797 × 10⁻⁷ | N·m·s
(KP) | 16.6742 | —
Practical Model 2 | 0.77 | 0.000 | 0.00000

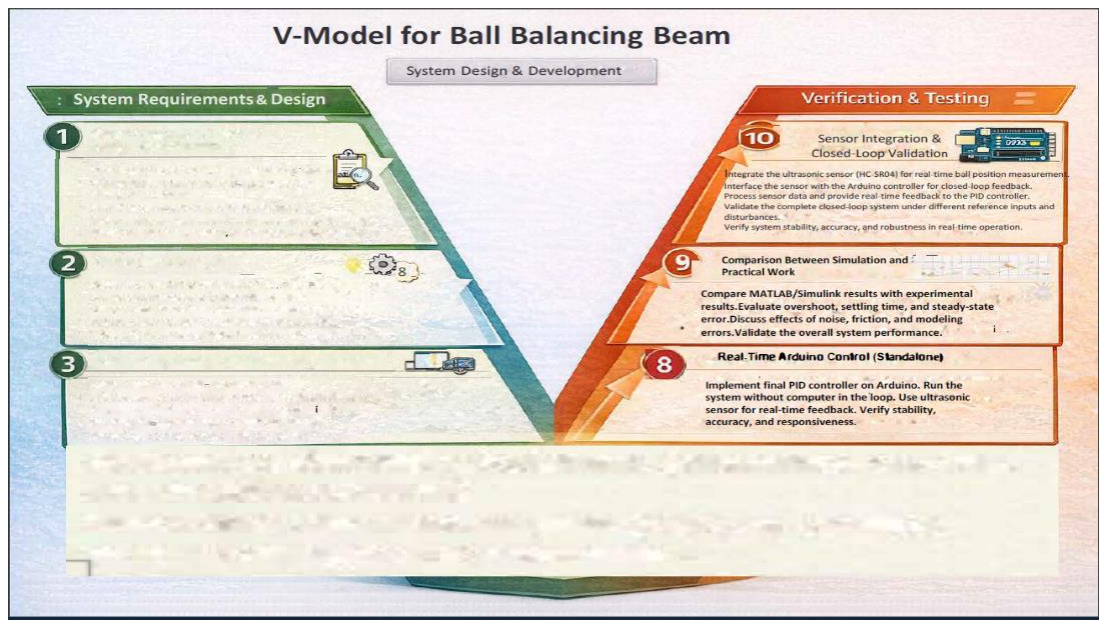
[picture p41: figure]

# Conclusion

The results obtained show that the collected data contained a small level of system deflection,

which had a noticeable effect on the motion of the ball. This deflection caused deviations from

the ideal behavior of the system and directly influenced the accuracy of the response. Several

attempts were made to compensate for this effect as much as possible, and through tuning and

adjustments, the system was able to reach a relatively stable operating condition.

During the experimental process, a clear difference was observed between the theoretical

calculations and the practical measurements. This difference was mainly due to the presence

of various sources of noise in the system. Significant noise was introduced by the ultrasonic

sensor, in addition to noise generated by the servo motor and other electronic components.

These noise sources accumulated and had a strong impact on the overall system response,

causing fluctuations, overshoot, and delays in the output signal.

Despite these challenges, it was concluded that the noise effects can be reduced and partially

controlled by applying an appropriate PID controller. By tuning the PID parameters, the system

response was improved, and a more acceptable level of stability and performance was achieved.

Although the response was not perfectly ideal, it became sufficiently reliable for practical

operation.

Finally, a comparison was made by plotting the system response for both the theoretical model

and the practical implementation. The plots showed noticeable differences in terms of

Figure 27:The right side of V-model overshoot, settling behavior, and overall dynamics. These differences confirm that real-world

systems are always affected by non-ideal factors such as noise, disturbances, and hardware

limitations. Nevertheless, the results demonstrate that with proper control techniques and

tuning, the system dynamics can be adjusted to obtain a reasonably acceptable and functional

response.

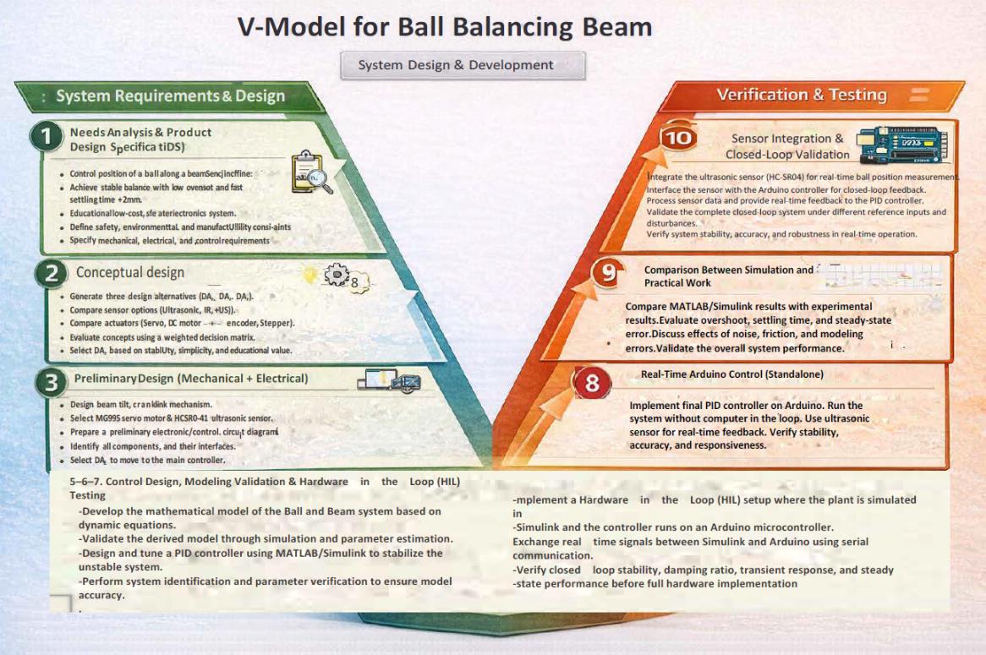
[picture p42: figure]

References

[1] Dr Amr Shafiq Lectures.
[2] Eng Mohamed Ashraf Section
[3] MathWorks, MATLAB and Simulink Documentation,

[4]https://www.mathworks.com/help

[5] MathWorks, System Identification Toolbox User’s Guide,

[6]https://www.mathworks.com/products/sysid.html

[7]MG995 Servo Motor Datasheet, TowerProhttps://www.towerpro.com.tw

[8] Arduino Documentation, https://www.arduino.cc/reference/en/ .

[9]Physical Modeling and Parameters Identification of the MG995 Servomotor paper

[10]https://ctms.engin.umich.edu/CTMS/index.php?example=BallBeam&section=Simulink

Modelingn (https://ctms.engin.umich.edu/CTMS/index.php?example=BallBeam&section=SimulinkModelingn)

Figure 28:The V-model

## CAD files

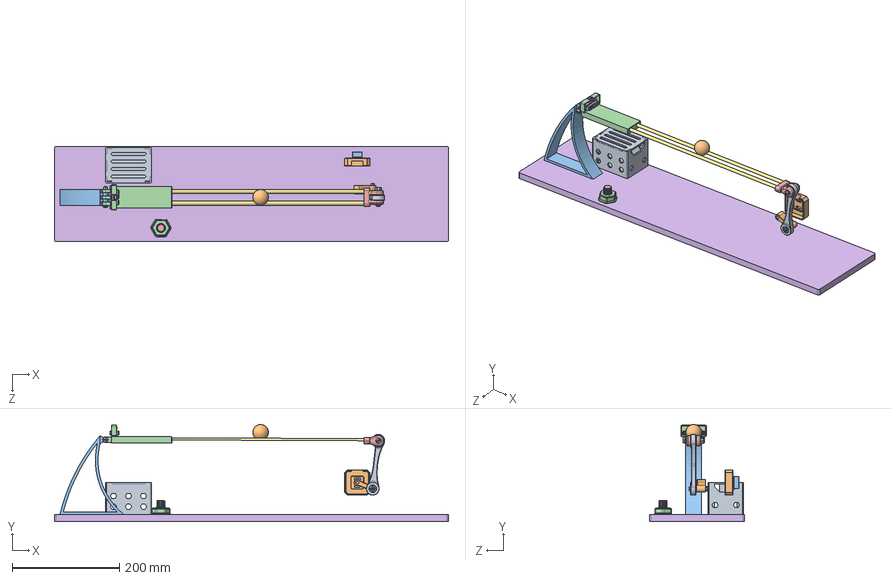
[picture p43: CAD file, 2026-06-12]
CAD/BALL AND BEAM ASSEMBLY.SLDASM
735.0 x 181.0 x 177.8 mm
Base
Beam End
Beam Hinge
Dowel x 2
Hinge Tower
605ZZ Bearing x 4
Crank
Coupler
ArduinoBoxTall
AS5600 NEMA-17 Mount
Encoder Cover
Potentiometer Holder
Potentiometer Knob
Long Range SHARP IR Sensors - #GP2Y0A21YK0F
binding head screw_ai x 2
hex nut style 1_am x 5
pan slot head_am x 3
ping pong ball

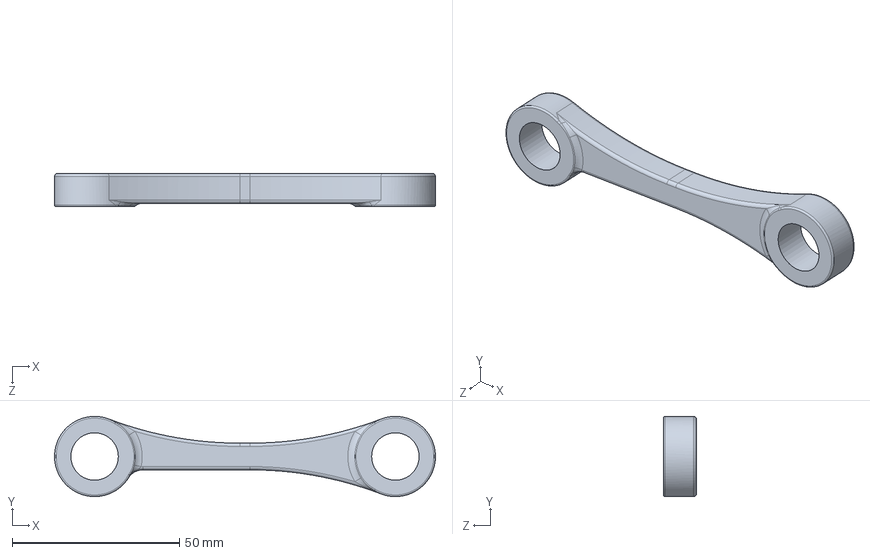
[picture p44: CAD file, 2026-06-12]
CAD/Coupler.SLDPRT
114.0 x 24.0 x 10.0 mm

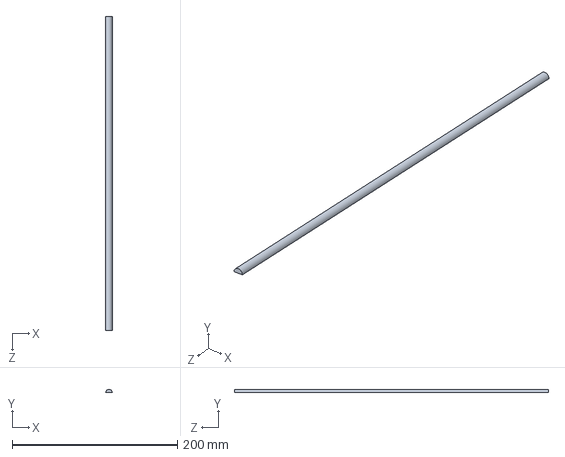
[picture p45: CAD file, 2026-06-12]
CAD/Dowel.SLDPRT
8.10 x 4.05 x 380.0 mm

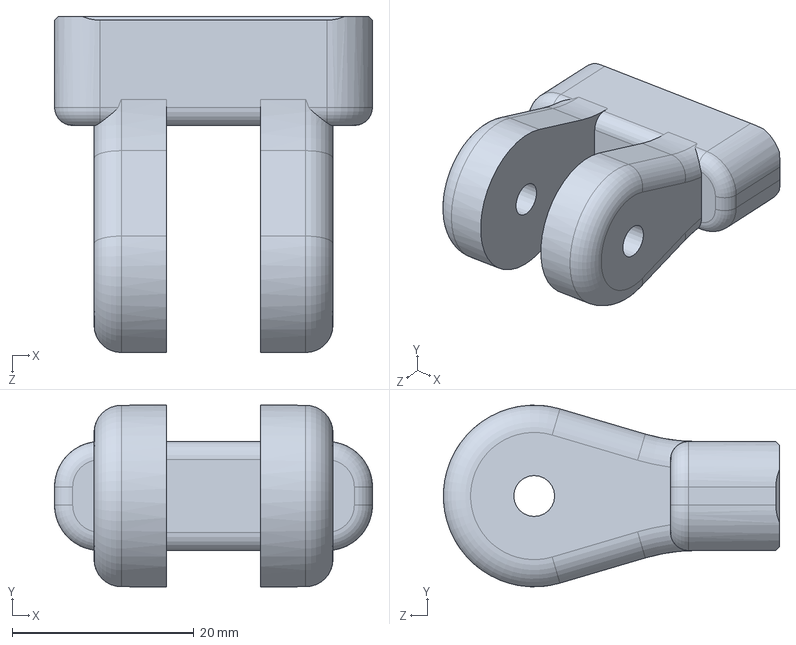
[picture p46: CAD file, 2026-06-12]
CAD/Beam End.SLDPRT
35.0 x 20.0 x 37.0 mm

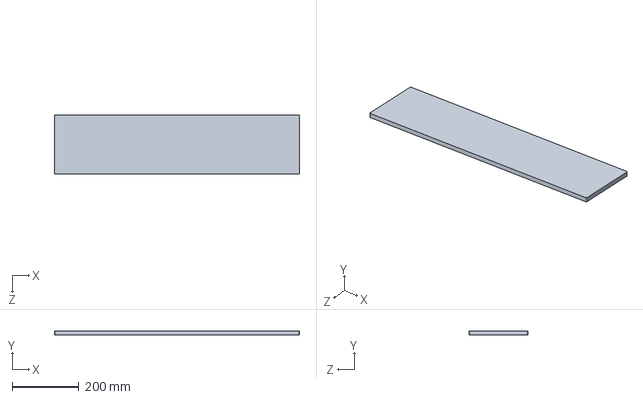
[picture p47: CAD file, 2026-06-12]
CAD/Base.SLDPRT
735.0 x 12.7 x 177.8 mm

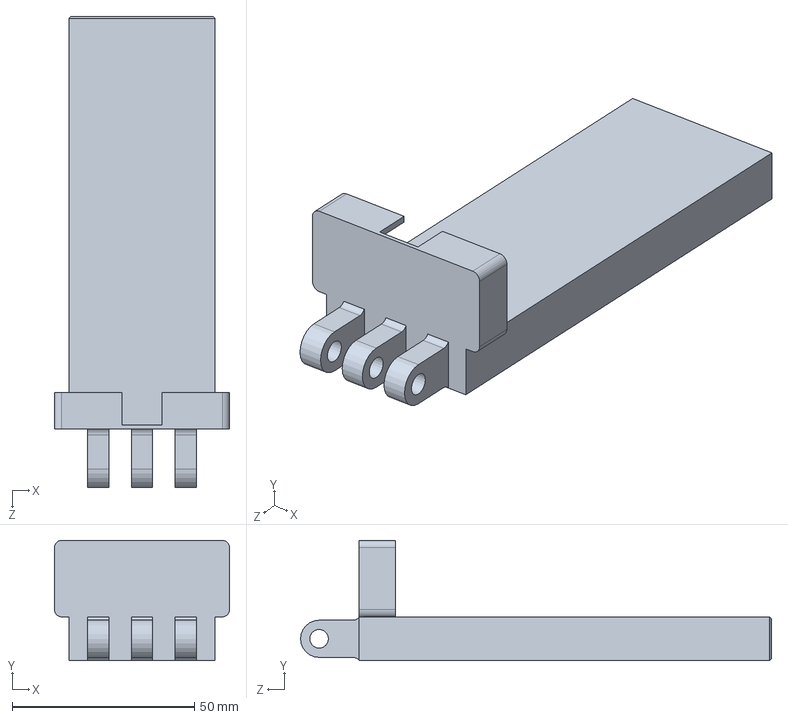
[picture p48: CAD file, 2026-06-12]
CAD/Beam Hinge.SLDPRT
48.0 x 33.0 x 129.1 mm

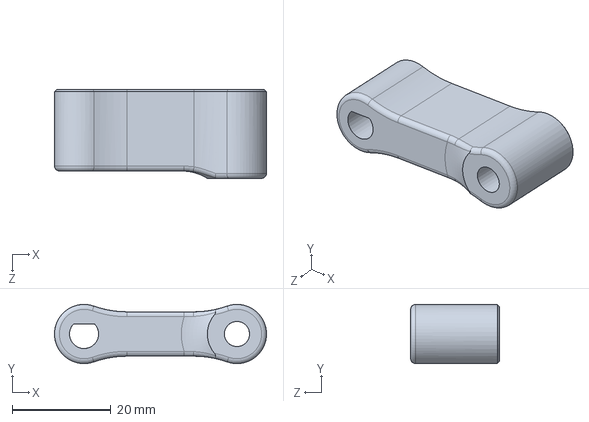
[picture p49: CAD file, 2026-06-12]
CAD/Crank.SLDPRT
43.0 x 12.0 x 18.0 mm

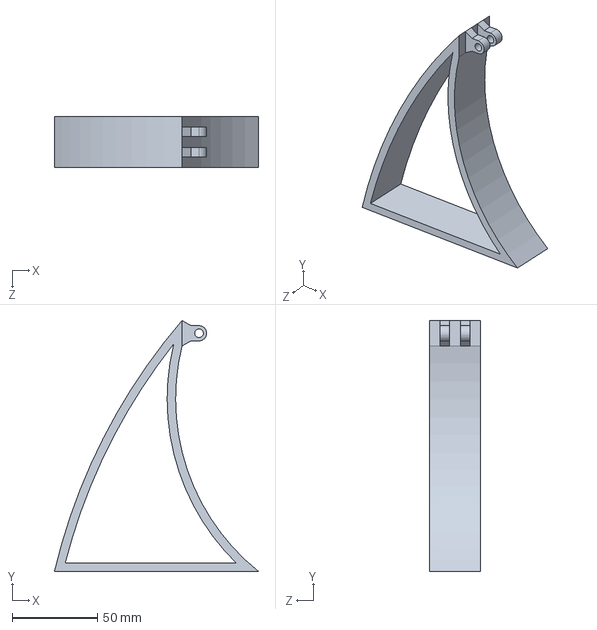
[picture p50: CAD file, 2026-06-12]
CAD/Hinge Tower.SLDPRT
120.0 x 147.5 x 30.0 mm
